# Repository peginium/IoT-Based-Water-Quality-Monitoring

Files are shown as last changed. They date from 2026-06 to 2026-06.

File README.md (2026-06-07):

# 💧 Smart Water Quality Monitoring System





An end-to-end, IoT-based Smart Water Quality Monitoring Station designed for real-time, in-situ analysis of water health. The system utilizes edge-processing to calculate a universal **Water Quality Index (WQI)** based on multiple sensor readings and streams JSON-formatted data wirelessly to a custom web dashboard.

Developed as a functional hardware-software integration project by **Chipware Labs**.

## ✨ Key Features
* **Real-Time Data Acquisition:** Simultaneously measures Temperature (°C), Total Dissolved Solids (TDS in ppm), and pH levels.
* **Edge Computing:** Performs hardware-level temperature compensation and WQI calculation directly on the MSP430 MCU.
* **Dual Visualization:** * *Local:* 0.96" I2C OLED display for immediate on-site readings.
  * *Remote:* Wireless transmission to a browser-based dashboard.
* **Web Serial API Dashboard:** Zero-server architecture. Connects directly to the HC-05 Bluetooth module via the browser to parse and display real-time JSON data.
* **Cascade Power Management:** Custom power distribution using LM7805 (5V) and LM1117T (3.3V) to ensure thermal stability and sensor accuracy.

## 🛠️ Hardware Architecture

### Components Used
* **MCU:** Texas Instruments MSP430G2553
* **Temperature Sensor:** DS18B20 (Waterproof, 1-Wire)
* **TDS Sensor:** Analog TDS Meter
* **pH Sensor:** DFRobot Gravity Analog pH Meter V2
* **Display:** Waveshare 0.96" OLED (I2C Mode)
* **Wireless Module:** HC-05 Bluetooth (UART)
* **Power:** 9V Battery + LM7805 & LM1117T-3.3 Regulators

### Pinout & Wiring Connections
| Module / Sensor | Pin / Function | MSP430G2553 Pin | Notes |
| :--- | :--- | :--- | :--- |
| **DS18B20** | DQ (Data) | `P2.0` | Requires a 4.7kΩ pull-up resistor to 3.3V. |
| **Analog TDS** | A0 (Signal) | `P1.4` (A4) | ADC input. Needs temperature compensation. |
| **Gravity pH V2** | A (Signal) | `P1.5` (A5) | ADC input. |
| **OLED Display**| SCL (Clock) | `P1.6` | I2C SCL. Requires 4.7kΩ pull-up resistor. |
| **OLED Display**| SDA (Data) | `P1.7` | I2C SDA. Requires 4.7kΩ pull-up resistor. |
| **HC-05** | TXD | `P1.1` (RXD) | Cross-connection for UART. |
| **HC-05** | RXD | `P1.2` (TXD) | Cross-connection for UART. |

> **⚠️ Important Hardware Note:** Ensure that the OLED's `CS` and `DC` pins are grounded to lock it into I2C mode (Address: `0x3C`), and tie the `RES` pin to 3.3V.

## 💻 Software Architecture
The embedded firmware is written in **C** using **Code Composer Studio (CCS)**. It focuses on lightweight operations to fit within the 16KB flash memory limit of the MSP430G2553.

* **Sensor Calibration:** Linear interpolation is used for pH, and active temperature compensation formula is applied to TDS readings.
* **WQI Algorithm:** A weighted arithmetic mean algorithm converts raw parameters into a single score (0-100) and categorizes water into *Excellent, Good, Poor, or Undrinkable*.
* **JSON Formatting:** To prevent memory overflow, custom string parsing algorithms are implemented instead of standard `sprintf` libraries. Data is packaged as `{"t":25.5,"tds":145,"ph":7.1,"wqi":85}\r\n`.

## 🚀 Installation & Setup

### 1. Embedded Firmware
1. Clone this repository: `git clone https://github.com/peginium/IoT-Based-Water-Quality-Monitoring.git`
2. Open **Code Composer Studio (CCS)** and import the project.
3. Build the project and flash it to the MSP430 Launchpad.
4. Wire the components according to the table above.

### 2. Web Dashboard
1. Power up the hardware system.
2. Pair your computer with the **HC-05** Bluetooth module (Default PIN is usually `1234` or `0000`).
3. Open the `index.html` file (located in the `/web` folder of this repo) using Google Chrome or Microsoft Edge.
4. Click the **Connect** button on the web page and select the Bluetooth COM port from the browser prompt.
5. Watch the real-time data flow!

## 👨‍💻 Author & Credits
* **Arhan Özcan**

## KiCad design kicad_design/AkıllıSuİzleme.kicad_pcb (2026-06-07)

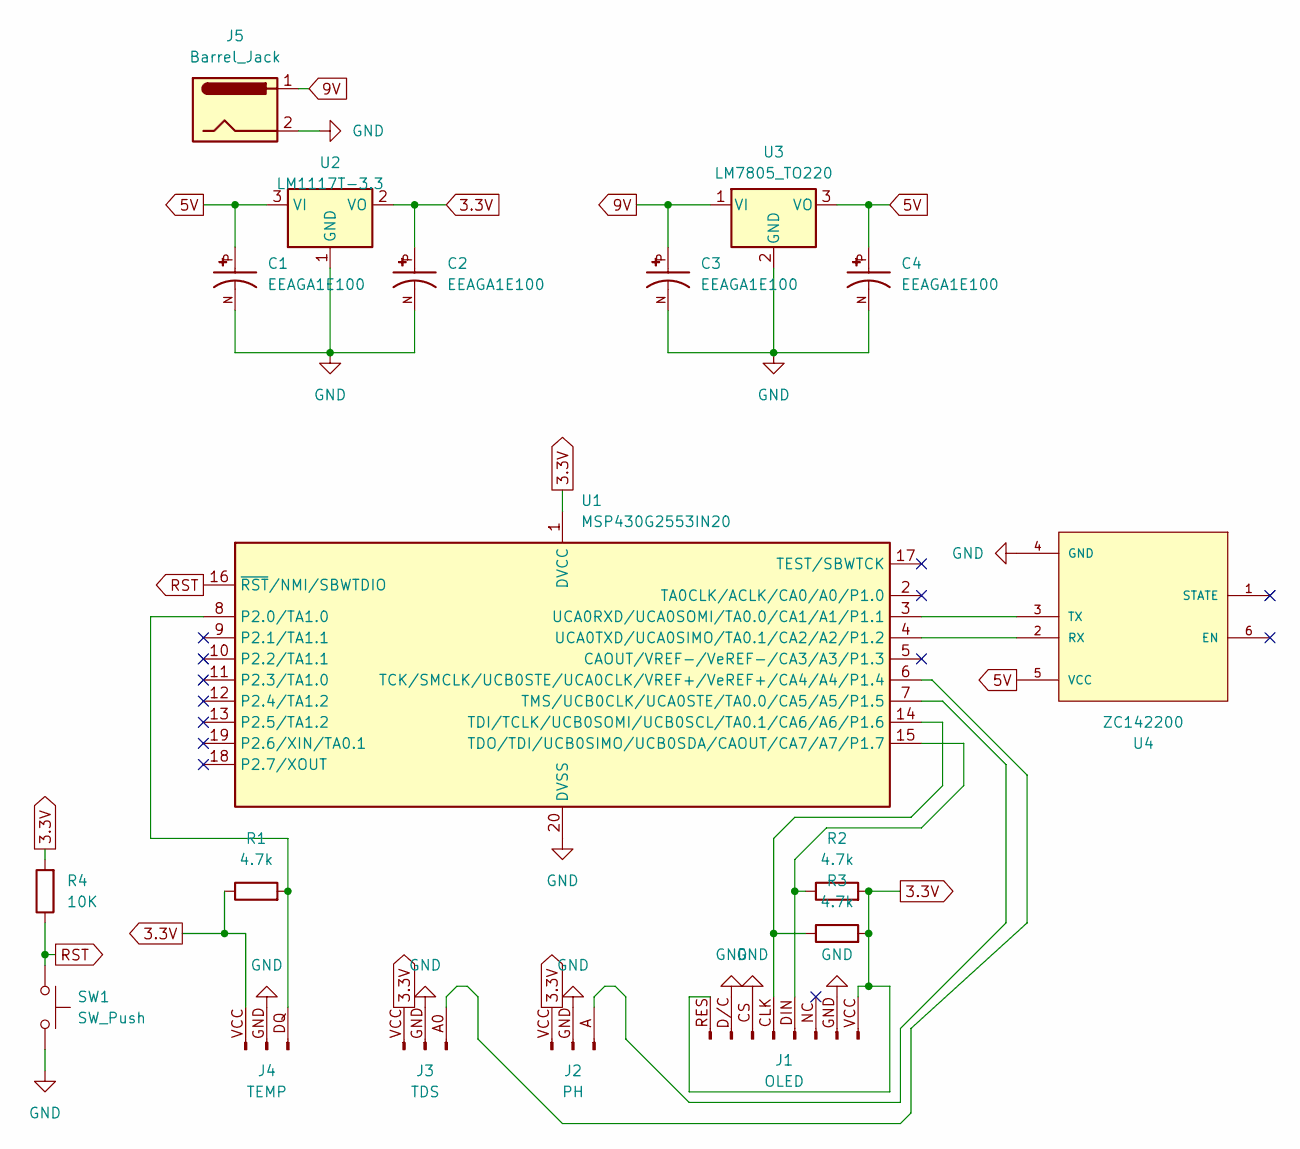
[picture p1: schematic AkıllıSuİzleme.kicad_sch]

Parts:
C1, C2, C3, C4: EEAGA1E100; C_Radial_D6.3mm_H7.0mm_P2.50mm; PARTREV 28-FEB-20
J1: OLED; PinHeader_1x08_P2.54mm_Vertical
J2: PH; PinHeader_1x03_P2.54mm_Vertical
J3: TDS; PinHeader_1x03_P2.54mm_Vertical
J4: TEMP; PinHeader_1x03_P2.54mm_Vertical
J5: Barrel_Jack; BarrelJack_SwitchcraftConxall_RAPC10U_Horizontal
R1, R2, R3: 4.7k; R_Axial_DIN0207_L6.3mm_D2.5mm_P10.16mm_Horizontal
R4: 10K; R_Axial_DIN0207_L6.3mm_D2.5mm_P10.16mm_Horizontal
SW1: SW_Push; SW_PUSH_1P1T_6x3.5mm_H5.0_APEM_MJTP1250
U1: MSP430G2553IN20; DIP-20_W7.62mm
U2: LM1117T-3.3; TO-220-3_Vertical
U3: LM7805_TO220; TO-220-3_Vertical
U4: ZC142200; MODULE_ZC142200; PARTREV N/A

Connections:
3.3V: C2.P, J1.RES (Pin_1), J1.VCC (Pin_8), J2.VCC (Pin_1), J3.VCC (Pin_1), J4.VCC (Pin_1), R1.1, R2.2, R3.2, R4.2, U1.1 (DVCC), U2.2 (VO)
5V: C1.P, C4.P, U2.3 (VI), U3.3 (VO), U4.5 (VCC)
9V: C3.P, J5.1, U3.1 (VI)
GND: C1.N, C2.N, C3.N, C4.N, J1.CS (Pin_3), J1.D/C (Pin_2), J1.GND (Pin_7), J2.GND (Pin_2), J3.GND (Pin_2), J4.GND (Pin_2), J5.2, SW1.2, U1.20 (DVSS), U2.1 (GND), U3.2 (GND), U4.4 (GND)
unnamed: J1.CLK (Pin_4), R3.1, U1.14 (TDI/TCLK/UCB0SOMI/UCB0SCL/TA0.1/CA6/A6/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)
unnamed: J1.DIN (Pin_5), R2.1, U1.15 (TDO/TDI/UCB0SIMO/UCB0SDA/CAOUT/CA7/A7/P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)
unnamed: J2.A (Pin_3), U1.7 (TMS/UCB0CLK/UCA0STE/TA0.0/CA5/A5/P1.5)
unnamed: J3.A0 (Pin_3), U1.6 (TCK/SMCLK/UCB0STE/UCA0CLK/VREF+/VeREF+/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)
unnamed: J4.DQ (Pin_3), R1.2, U1.8 (P2.0/TA1.0)
unnamed: U1.3 (UCA0RXD/UCA0SOMI/TA0.0/CA1/A1/P1.1), U4.3 (TX)
unnamed: U1.4 (UCA0TXD/UCA0SIMO/TA0.1/CA2/A2/P1.2), U4.2 (RX)
RST: R4.1, SW1.1, U1.16 (~RST/NMI/SBWTDIO)

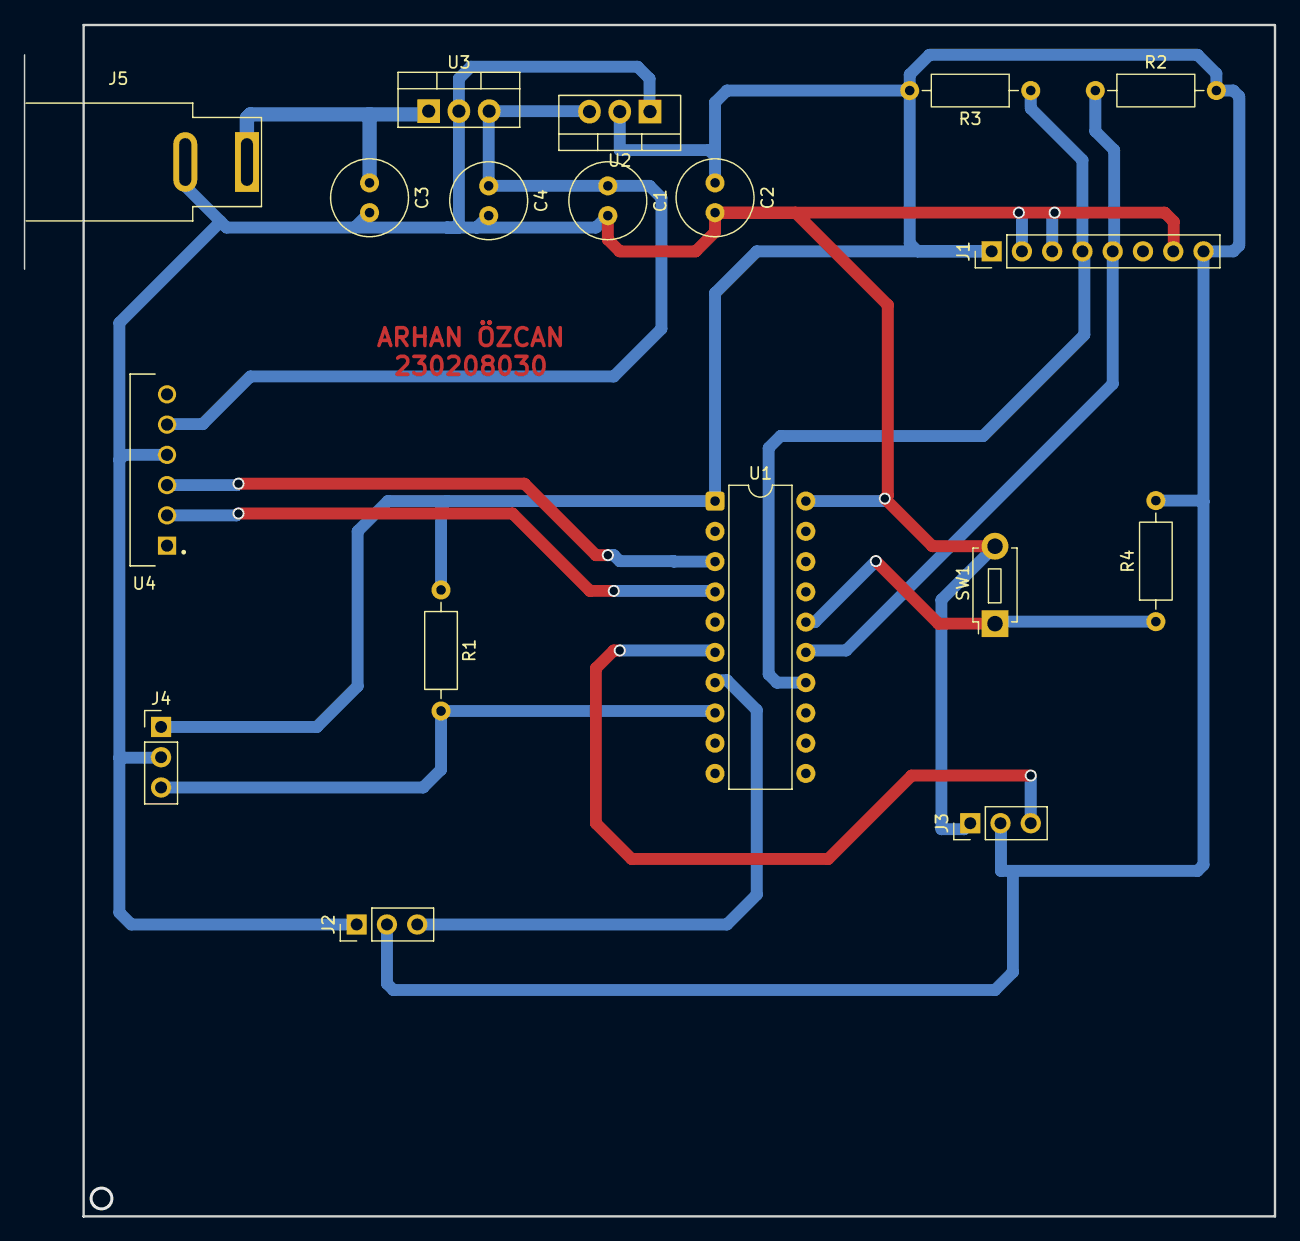
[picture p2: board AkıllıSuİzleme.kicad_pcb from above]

Board: 2 copper layers, 105.0 x 100.0 mm, 18 parts (0 on the bottom side), 12 nets.

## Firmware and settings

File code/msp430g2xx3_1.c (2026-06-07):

#include <msp430.h>
#include <stdint.h>
#include "i2c.h"
#include "ssd1306.h"
#include "ds18b20.h"

// ==========================================
// --- UART (HC-05) BAŞLATMA FONKSİYONLARI ---
// ==========================================
void uart_init(void) {
    P1SEL |= BIT1 + BIT2;
    P1SEL2 |= BIT1 + BIT2;
    
    UCA0CTL1 |= UCSSEL_2;
    UCA0BR0 = 104;
    UCA0BR1 = 0;
    UCA0MCTL = UCBRS0;
    UCA0CTL1 &= ~UCSWRST;
}

void uart_print(char *str) {
    while (*str != '\0') {
        while (!(IFG2 & UCA0TXIFG));
        UCA0TXBUF = *str++;
    }
}

// ==========================================
// --- ADC10  ---
// ==========================================
void adc_init(void) {
    ADC10CTL0 = SREF_0 + ADC10SHT_2 + ADC10ON;   
    ADC10AE0 |= BIT4 + BIT5;
}

uint16_t adc_read(uint8_t channel) {
    ADC10CTL0 &= ~ENC;                           
    ADC10CTL1 = (channel << 12) + SHS_0 + ADC10DIV_0 + ADC10SSEL_0; 
    ADC10CTL0 |= ENC + ADC10SC;                  
    while (ADC10CTL1 & ADC10BUSY);               
    return ADC10MEM;                             
}

// ==========================================
// --- ANA PROGRAM ---
// ==========================================
void main(void) {
    WDTCTL = WDTPW + WDTHOLD;                    

    if (CALBC1_1MHZ == 0xFF) { while(1); }
    DCOCTL = 0;
    BCSCTL1 = CALBC1_1MHZ;
    DCOCTL = CALDCO_1MHZ;

    __delay_cycles(100000);                      

    i2c_init();                               
    ssd1306_init();                           
    ssd1306_clearDisplay();                   
    adc_init();
    uart_init();

    ssd1306_printText(0, 0, "--- SU KALITESI ---");
    ssd1306_printText(0, 2, "Temp :");
    ssd1306_printText(0, 3, "TDS  :");
    ssd1306_printText(0, 4, "pH   :");
    ssd1306_printText(0, 6, "Genel WQI :");

    while(1) {
        char temp_str[10] = "0.0"; 
        char ph_str[6] = "0.0";
        
        // --- 1. SICAKLIK OKUMA (DS18B20) ---
        int16_t raw_temp = ds18b20_get_temp();
        float gercek_sicaklik = 25.0; 
        
        if (raw_temp != 9999) {
            int16_t tam_kisim = raw_temp >> 4;
            int16_t ondalik_kisim = ((raw_temp & 0x0F) * 10) / 16; 
            gercek_sicaklik = (float)tam_kisim + ((float)ondalik_kisim / 10.0);

            temp_str[0] = (tam_kisim / 10) + '0'; 
            temp_str[1] = (tam_kisim % 10) + '0'; 
            temp_str[2] = '.';                    
            temp_str[3] = ondalik_kisim + '0';    
            temp_str[4] = '\0';
            
            ssd1306_printText(50, 2, temp_str);
            ssd1306_printText(75, 2, "C");
        } else {
            temp_str[0] = '0'; temp_str[1] = '\0';
            ssd1306_printText(50, 2, "HATA ");
        }

        // --- 2. TDS OKUMA VE HESAPLAMA (P1.4) ---
        uint16_t tds_adc = adc_read(4); 
        float tds_voltaj = ((float)tds_adc / 1023.0) * 3.3;
        float tds_kompanzasyon = 1.0 + 0.02 * (gercek_sicaklik - 25.0);
        float tds_komp_voltaj = tds_voltaj / tds_kompanzasyon;
        
        float tds_degeri = (133.42 * tds_komp_voltaj * tds_komp_voltaj * tds_komp_voltaj 
                          - 255.86 * tds_komp_voltaj * tds_komp_voltaj 
                          + 857.39 * tds_komp_voltaj) * 0.5;
        if (tds_degeri < 0) tds_degeri = 0;

        uint32_t final_tds = (uint32_t)tds_degeri;
        ssd1306_printText(50, 3, "        "); 
        ssd1306_printUI32(50, 3, final_tds, 0);
        ssd1306_printText(80, 3, "ppm");

        // --- 3. pH OKUMA VE HESAPLAMA (P1.5) ---
        uint16_t ph_adc = adc_read(5);  
        float ph_voltaj = ((float)ph_adc / 1023.0) * 3.3;
        float ph_degeri = 7.0 + ((1.5 - ph_voltaj) / 0.18);
        
        if (ph_degeri < 0.0) ph_degeri = 0.0;
        if (ph_degeri > 14.0) ph_degeri = 14.0;

        int16_t ph_tam = (int16_t)ph_degeri;
        int16_t ph_ondalik = (int16_t)((ph_degeri - ph_tam) * 10);
        
        ph_str[0] = (ph_tam / 10) ? ((ph_tam / 10) + '0') : ' '; 
        ph_str[1] = (ph_tam % 10) + '0';
        ph_str[2] = '.';
        ph_str[3] = ph_ondalik + '0';
        ph_str[4] = '\0';
        
        ssd1306_printText(50, 4, "      "); 
        ssd1306_printText(50, 4, ph_str);

        // --- 4. WQI (WATER QUALITY INDEX) HESABI ---
        float ph_fark = ph_degeri - 7.0;
        if (ph_fark < 0) ph_fark = -ph_fark; 
        float q_ph = 100.0 - (ph_fark * 20.0);
        if (q_ph < 0) q_ph = 0;

        float q_tds = 100.0 - (tds_degeri / 5.0); 
        if (q_tds < 0) q_tds = 0;

        float temp_fark = gercek_sicaklik - 22.0;
        if (temp_fark < 0) temp_fark = -temp_fark; 
        float q_temp = 100.0 - (temp_fark * 3.0);
        if (q_temp < 0) q_temp = 0;

        uint8_t wqi_skoru = (uint8_t)((q_ph * 0.45) + (q_tds * 0.45) + (q_temp * 0.10));

        ssd1306_printText(75, 6, "   "); 
        ssd1306_printUI32(75, 6, wqi_skoru, 0);
        ssd1306_printText(100, 6, "/100");

        ssd1306_printText(0, 7, "Durum: ");
        if (wqi_skoru >= 80)      ssd1306_printText(40, 7, "MUKEMMEL ");
        else if (wqi_skoru >= 60) ssd1306_printText(40, 7, "IYI      ");
        else if (wqi_skoru >= 40) ssd1306_printText(40, 7, "ZAYIF    ");
        else                      ssd1306_printText(40, 7, "ICILEMEZ!");

        // --- 5. BLUETOOTH (HC-05) İLE VERİ AKTARIMI (JSON FORMATI) ---
        uart_print("{\"t\":");
        uart_print(temp_str);
        
        uart_print(",\"tds\":");
        char buffer_tds[10];
        ssd1306_ultoa(final_tds, buffer_tds);  
        uart_print(buffer_tds);
        
        uart_print(",\"ph\":");
        uart_print(ph_str);                    
        
        uart_print(",\"wqi\":");
        char buffer_wqi[10];
        ssd1306_ultoa(wqi_skoru, buffer_wqi);
        uart_print(buffer_wqi);
        
        uart_print("}\r\n");

        __delay_cycles(1000000);
    }
}
